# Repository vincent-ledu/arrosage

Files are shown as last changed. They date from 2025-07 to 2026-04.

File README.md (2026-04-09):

# Description

🌍 **This project automates the watering of a garden** using a Raspberry Pi connected to a rainwater collector.

🌊 It monitors water levels with floating switches and controls a solenoid valve and pump to distribute water as needed.

🔧 The system is designed for reliability and ease of installation, using readily available components and open-source software.

🌿 **Goal**: Optimize water usage and reduce manual intervention for garden irrigation.

💡 This project is completely inspired by Frederic JELMONI's project, available here: [Fred's Project](https://www.fred-j.org/index0364.html?p=364)

# Features

- 🌡️ **Retrieves daily temperature forecasts** from Open-Meteo to optimize watering schedules.
- 💦 **Adjusts watering duration and frequency** based on the predicted maximum temperature of the day.
- 🌊 **Displays real-time water tank level** using floating switches.
- 📊 **Shows a history of past watering events** for monitoring and analysis.

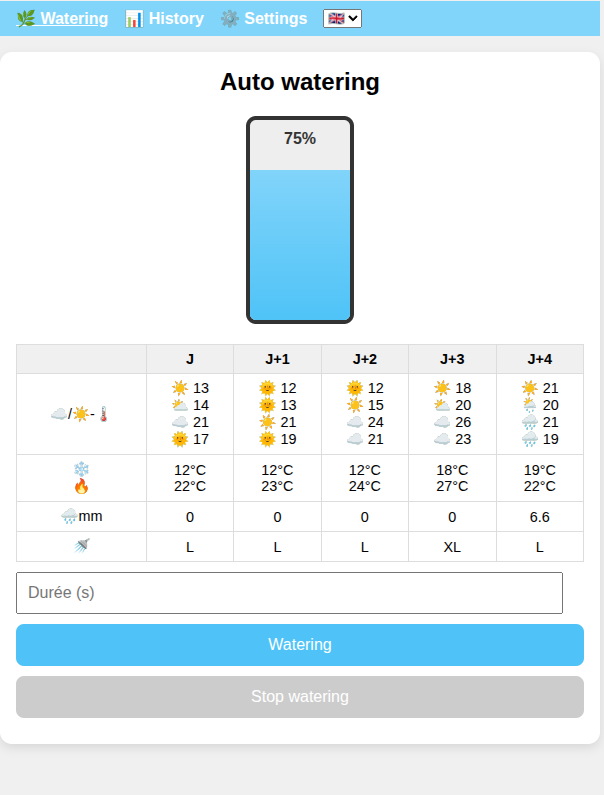
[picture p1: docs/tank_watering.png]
Tank monitor and watering control


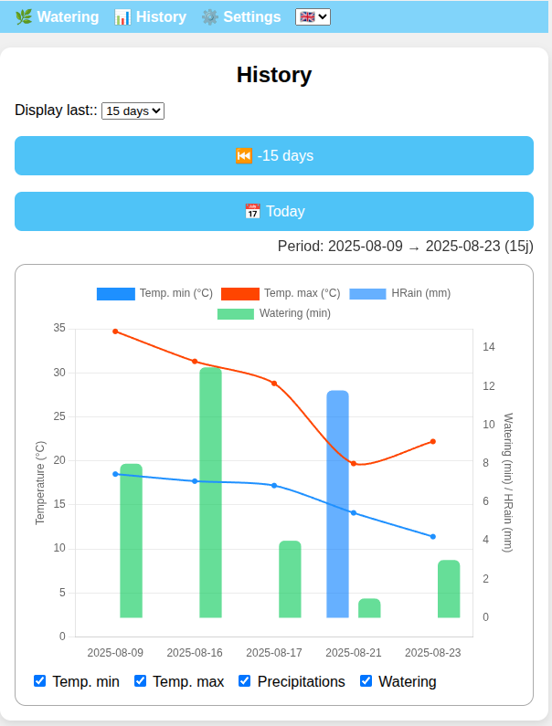
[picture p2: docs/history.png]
Graph of watering history


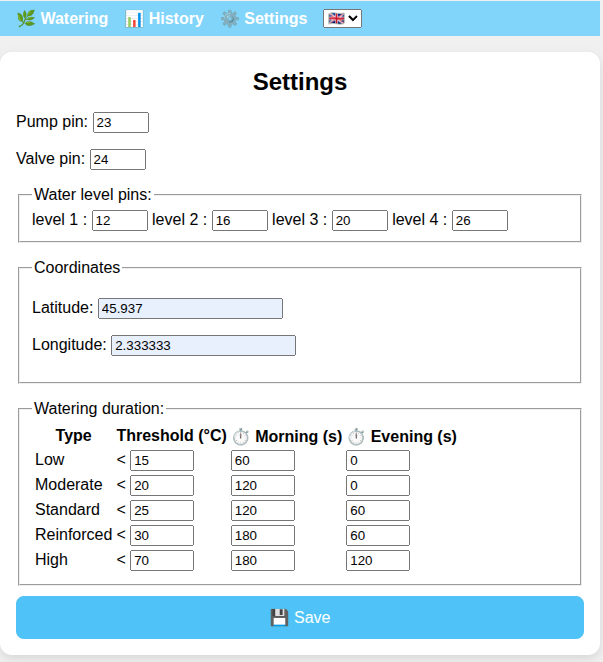
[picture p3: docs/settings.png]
Settings


# Electronic and soldering

## Wiring for water detection in the tank

For this part, the best is to consult [Fred's Project](https://www.fred-j.org/index0364.html?p=364)

My customisation:

- I didn't use hat, I just solder cable directory on resistors, and protect with heat shrink tubes.
- I just use 4 floating switches. I need only these level:
  - Full, to potentielly stop collecting water
  - Empty, to stop all watering process
  - Two intermediates levels, for information
- To compute water level, we count number of floating switch. It simplifies wiring.

Here is the electronic diagram from Frédéric JELMONI's project:
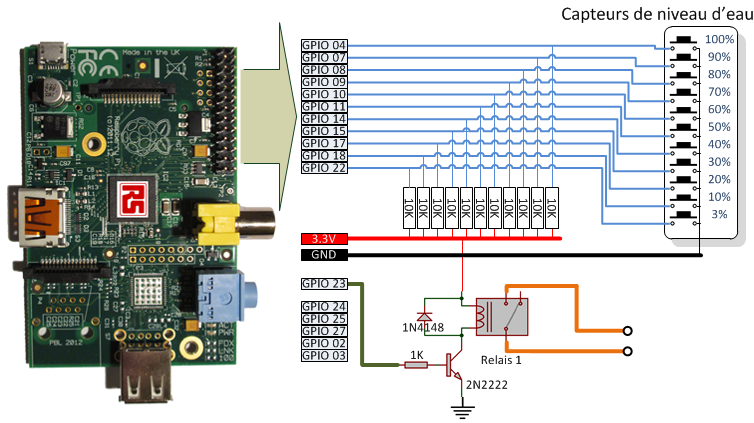
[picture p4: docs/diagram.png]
Wiring diagram


## Wiring for pump and valve

My pump need to be plug in a standard electric outlet.

So, I wire an eletric outlet with the 5V Low Level trigger.

The valve has to be pluged with cable directly to the 5V low level trigger.

# Configuration

🖥️ **Tested on Raspberry Pi 1 and 4.**

🔧 **Middlewares installed:**

- nginx, as reverse proxy and protect access to sensitive action (watering, gpio pin settings, ...) from outside the lan network.
- gunicorn, as wsgi python server. As mentionned when you start a python Flask project, default webserver in Flask is not to use in production.
- mariadb, as database. Tried with SQLite, but it's a big crap, specially for datetime...

⚙️ **Specific Configuration:**

- Adding `www-data` user to the GPIO group

# 🏡 My architecture

```mermaid
flowchart LR
    A(["Internet Box"]) --> B{"Security<br>Reverse<br>Proxy"}
    B --> C["PI<br>Watering project"] & X["Others apps"]
    C --> D("Pump") & E("Valve") & F("Tank")
     A:::Rose
     B:::Peach
     C:::Sky
     X:::Ash
     D:::Aqua
     E:::Aqua
     F:::Aqua
    classDef Rose stroke-width:1px, stroke-dasharray:none, stroke:#FF5978, fill:#FFDFE5, color:#8E2236
    classDef Peach stroke-width:1px, stroke-dasharray:none, stroke:#FBB35A, fill:#FFEFDB, color:#8F632D
    classDef Sky stroke-width:1px, stroke-dasharray:none, stroke:#374D7C, fill:#E2EBFF, color:#374D7C
    classDef Aqua stroke-width:1px, stroke-dasharray:none, stroke:#46EDC8, fill:#DEFFF8, color:#378E7A
    classDef Ash stroke-width:1px, stroke-dasharray:none, stroke:#999999, fill:#EEEEEE, color:#000000
```

## VM for security

Installed middlewares:

- NGinx: Reverse Proxy as unique entry-point, to handle basically on premise hosting redirection
  - It has reinforced nginx settings
  - Handle Let's Encrypt certificate
- Fail2ban: Trap and ip ban bots and malicious scan

## Raspberry

Installed middlewares:

- NGinx:
  - Reverse proxy, with security specific directive to forbid sensitive action coming outside LAN network: Watering, GPIO pin setting, coordinates, ...
  - this nginx configuration file is present in this repository, in deployment folder
- Gunicorn: As mentionned when you start a flask application in development, you must use a wsgi server for production environment.
  - Systemd config file for gunicorn is present in deployment folder.

## Deployment script

See `utils/deploy.sh`

## Crontab

```bash
### morning
0 6 * * * cd /opt/arrosage/current && /opt/arrosage/current/.venv/bin/python scripts/cron.py morning >> /var/log/gunicorn/cron-arrosage.log 2>&1
### evening
0 20 * * * cd /opt/arrosage/current && /opt/arrosage/current/.venv/bin/python scripts/cron.py evening >> /var/log/gunicorn/cron-arrosage.log 2>&1
```

# TODO

- [ ] 🚿 Compute water volume per watering (settings with pump capacity)

# DONE

- [x] 👾 Analyze warning message in venv creation and dependancies installation
- [x] 🏗️ Go to a Domain Driven Design approach
- [x] 🇫🇷/🇬🇧 Fix translation bug
- [x] 🌦️ Give temperature and precipitation forecast for next 3 days
- [x] 🖼️ Add some pictures of the electrical device
- [x] 🌡️ Table from j-0 to J+4, with cloud, morning/evening, temperature
- [x] 🌡️ Get and display min/max temperature of the day
- [x] 📊 Review data model to integrate : start and stop for water tasks, temperature & precip
- [x] 📊 Review graph: add min max temperature, precipitation, last 30 days
- [x] 🔥 Add temperature to history graph
- [x] 💬 Investigate "Message flash" in flask for user error display
- [x] 👾 Fix front (flag, white main zone, textbox width, label for Rain, get current watering task...)
- [x] 📊 Review graph: improve data model
  - [x] #️⃣ create a separate table for temperature, precipitations
  - [x] #️⃣ import data
  - [x] 📊 make a join for history display
- [x] 🏎️ Add data in cache for data of the day
- [x] 🧪 Improve unittest
  - [x] 📊 Bind to test instance database
  - [x] 🧪 Add more unit tests
- [x] 🚚 Review deploy script
  - [x] 🚚 Remove sqlite backup
  - [x] ➕ Add mariadb backup
- [x] 🧊 Prevent watering when temperature < 0°
- [x] 🗓️ Settings for month watering: checks which month watering is enabled
- [x] 🏎️ Improve cached data
  - [x] 📊 Rename existing table to weather_data
  - [x] 📊 Create table to forecat_data
  - [x] ⏱️ Refresh weather data of the day for 6h.
  - [x] 🧪 Unit testing
  - [x] 🏎️ Cache forecat for 4 next days (j+1 to j+4) in table forecast_data
  - [x] ⏱️ Cache forecat data for 6h.
  - [x] ❌ Delete old forecast data
  - [x] 🧪 Unit testing
- [x] 💬 Fix message flash when non page redirect

# Inventory

## Electrical Devices ⚡

- 🍓 **Raspberry Pi (Model 3 here)**  
  [Amazon Link](https://www.amazon.fr/Raspberry-d%C3%A9marrage-dalimentation-Bo%C3%AEtier-Carte/dp/B0D3FNL84M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) ~72€
- 💧 **4 Floating Water Switch to detect water level**  
  [Amazon Link](https://www.amazon.fr/dp/B0DD6L4QP6?ref=ppx_yo2ov_dt_b_fed_asin_title) ~2x10€

- 🔌 **Wires to link from the tank to the Raspberry Pi**  
  [Amazon Link](https://www.amazon.fr/dp/B0087YHNGK?ref=ppx_yo2ov_dt_b_fed_asin_title) ~20€

- 🪛 **10KOhm Resistors**  
  [Amazon Link](https://www.amazon.fr/Innfeeltech-tol%C3%A9rance-r%C3%A9sistance-m%C3%A9tallique-exp%C3%A9riences/dp/B0CL6MDSHV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) ~7€

- 🔋 **5V Low Level Trigger**  
  [Amazon Link](https://www.amazon.fr/dp/B07LB2RQYP?ref=ppx_yo2ov_dt_b_fed_asin_title) ~13€

- 🔧 **Heat Shrink Tubing**  
  [Amazon Link](https://www.amazon.fr/dp/B084GDLSCK?ref=ppx_yo2ov_dt_b_fed_asin_title) ~15€

- 📦 **IP55 Large Box**  
  [Amazon Link](https://www.amazon.fr/dp/B003O2X6T8?ref=ppx_yo2ov_dt_b_fed_asin_title) ~30€

- 🚿 **Solenoid Valve**  
  [Amazon Link](https://www.amazon.fr/dp/B0BRCPP7ZZ?ref=ppx_yo2ov_dt_b_fed_asin_title) ~25€

- 🔌 **Dupont Cables**  
  [Amazon Link](https://www.amazon.fr/Elegoo-Breadboard-Femelle-Longueur-Arduino/dp/B01JD5WCG2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) ~10€

- 🧰 **Breadboard**  
  [Amazon Link](https://www.amazon.fr/sspa/click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) ~7€

- ⚙️ **Metal Angle to screw floating water switch in the tank** [Amazon link](https://www.amazon.fr/Commentfer-Corniere-acier-Longueur-metres/dp/B01N02DVJ0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)

**Total: ~220€**

## Garden Devices 🌳

- 🚰 **Water Pump**  
  [Amazon Link](https://www.amazon.fr/dp/B08MV3VW7S?ref=ppx_yo2ov_dt_b_fed_asin_title) ~80€

- 🌿 **Garden Hose Connection**  
  [Amazon Link](https://www.amazon.fr/dp/B0BZKP7CNV?ref=ppx_yo2ov_dt_b_fed_asin_title) ~10€

- 💦 **Quick Garden Hose Connection**  
  [Amazon Link](https://www.amazon.fr/dp/B09J93FDK2?ref=ppx_yo2ov_dt_b_fed_asin_title) ~10€

**Total: ~100€**

# Installation prerequisites

```bash
apt update
apt install nginx mariadb-server build-essential python3-dev
mkdir /run/gunicorn
chown www-data:www-data /run/gunicorn
usermod -a -G gpio www-data
mysql -u root -p < utils/create-database.sql
```

## Tools 🔧

- 🔩 Screwdrivers
- 🔥 Soldering Iron
- 🧲 Tin
- 🔩 Screws
- 🔥 Heat Gun

# Credits

Pictures and diagrams from Frédéric JELMONI is used with his consent.

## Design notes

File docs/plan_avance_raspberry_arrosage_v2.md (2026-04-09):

# Plan avancé Raspberry Pi arrosage (v2)

## 🔋 Schéma condensateurs

5V ───┬──[100nF]── GND
      │
      └──[470µF]── GND

3.3V ───┬──[100nF]── GND
        │
        └──[100µF]── GND

GPIO ───┬── flotteur ─── GND
        │
       [100nF]
        │
       GND

230V : snubber RC parallèle

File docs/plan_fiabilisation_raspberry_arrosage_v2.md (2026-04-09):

# Plan de fiabilisation Raspberry Pi arrosage (v2)

## 🔋 Condensateurs

### 5V relais
5V ───┬──[100nF]── GND
      │
      └──[470µF]── GND

### 3.3V capteurs
3.3V ───┬──[100nF]── GND
        │
        └──[100µF]── GND

### GPIO flotteurs
GPIO ───┬── flotteur ─── GND
        │
       [100nF]
        │
       GND

### 230V
Snubber RC sur charge

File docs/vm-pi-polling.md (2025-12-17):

# VM side – Pi polling & cache

Objectif : l’UI/back reste disponible même si le Raspberry Pi est instable.
La VM poll périodiquement le `pi-service` et stocke le dernier état connu en DB.

## Variables d’environnement (VM)

Dans `/etc/default/arrosage` :

- `PI_SERVICE_URL=http://<pi-host>` (obligatoire pour activer le mode Pi)
- `PI_SERVICE_TOKEN=...` (recommandé)
- `PI_SERVICE_TIMEOUT_CONNECT=0.5`
- `PI_SERVICE_TIMEOUT_READ=1.0`
- `PI_SNAPSHOT_MAX_AGE_SEC=120`

## Cache en base

- Table `device_snapshot` : dernier état connu (niveau d’eau, watering, last_seen_at…)
- Table `device_command_log` : audit des commandes start/stop

Migration Alembic : `migrations/versions/7_0f1caa2f4cbb_create_device_snapshot_and_logs.py`

## Poller

Script : `scripts/pi_poll.py`

Option systemd timer (recommandé) :

- Service : `deployment/systemd/arrosage-pi-poll.service`
- Timer : `deployment/systemd/arrosage-pi-poll.timer`

Installation (sur la VM) :

- `sudo cp /opt/arrosage/current/deployment/systemd/arrosage-pi-poll.service /etc/systemd/system/`
- `sudo cp /opt/arrosage/current/deployment/systemd/arrosage-pi-poll.timer /etc/systemd/system/`
- `sudo systemctl daemon-reload`
- `sudo systemctl enable --now arrosage-pi-poll.timer`

## Endpoints VM

- `GET /api/water-level` : sert le cache DB (fallback 0 si pas de cache)
- `GET /api/device/snapshot` : détail du snapshot + stale/age
- `GET /api/device/gpio?verbose=1` : proxy live vers le Pi (si disponible)

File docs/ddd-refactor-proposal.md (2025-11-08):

# Proposition de refonte Domain-Driven Design

## Constats sur l'existant

* `app/app.py` concentre la configuration Flask, des appels HTTP externes, des accès SQLAlchemy et la gestion temps-réel du matériel (pompe, vannes, flotteurs). 【F:app/app.py†L1-L454】
* Les accès à la base (`app/db`) exposent directement l'ORM aux couches supérieures, ce qui couple l'API au schéma relationnel. 【F:app/db/db_tasks.py†L18-L80】
* Le contrôle matériel est instancié en global selon l'environnement, ce qui rend difficile le remplacement dans des scénarios métiers. 【F:app/app.py†L25-L37】

Ces éléments mélangent responsabilités applicatives, domaine et infrastructure, compliquant l'évolution vers de nouvelles règles d'arrosage.

## Bounded contexts proposés

| Contexte | Responsabilité | Entités / Agrégats | Interfaces externes |
| --- | --- | --- | --- |
| **WateringControl** | Pilotage des tâches d'arrosage (durée, annulation, statut) | `WateringTask`, `WateringSchedule` | GPIO/contrôleur matériel |
| **WaterResource** | Mesure et alerte sur le niveau d'eau disponible | `TankLevel`, `WaterAvailability` | Capteurs de niveau |
| **WeatherInsight** | Collecte et agrégation des prévisions météo | `DailyForecast`, `PartDayForecast` | API Open-Meteo |
| **SystemConfiguration** | Paramétrage utilisateur (coordonnées, mois actifs, seuils) | `WateringPolicy` | Fichier de configuration |

Chaque contexte expose des services applicatifs explicites et des ports (interfaces) vers l'infrastructure.

## Strate d'architecture (hexagone inspiré DDD)

```
domain/
  watering/
    entities.py        # WateringTask, TankLevelSnapshot
    policies.py        # Règles métier (mois actifs, températures)
    services.py        # e.g. WateringScheduler
  weather/
    value_objects.py
    services.py        # Agrégations sur les prévisions
  configuration/
    repositories.py    # Port vers le stockage de configuration
application/
  watering/
    commands.py        # StartWatering, StopWatering
    queries.py         # FetchCurrentTask
    handlers.py        # Orchestration des entités et ports
infrastructure/
  persistence/
    watering_task_repository.py
    weather_repository.py
  devices/
    gpio_controller.py
  external/
    open_meteo_client.py
interfaces/
  http/
    flask/
      routes/
  cli/
```

* **Domain** : entités riches, règles (`WateringPolicy`) calculant la durée selon la température, validations de disponibilité d'eau.
* **Application** : orchestrateurs qui orchestrent les ports (`WateringTaskRepository`, `WeatherForecastProvider`, `DeviceController`). Les commandes/queries remplacent les routes lourdes de `app/app.py`. 【F:app/app.py†L280-L433】
* **Infrastructure** : implémentations SQLAlchemy/GPIO/API des ports. `db_tasks` devient une implémentation de `WateringTaskRepository`. 【F:app/db/db_tasks.py†L18-L80】
* **Interfaces** : routes Flask deviennent de simples adaptateurs qui traduisent HTTP ↔ commandes applicatives.

## Ports et adapters clés

| Port | Contrat | Adapter initial |
| --- | --- | --- |
| `DeviceController` | `open_water(duration)`, `close_water()`, `read_tank_level()` | `GPIOControl` / `FakeControl` (déplacés sous `infrastructure.devices`) 【F:app/app.py†L25-L37】|
| `WateringTaskRepository` | CRUD des tâches, recherche par statut | `db_tasks` (renommé, injecté) 【F:app/db/db_tasks.py†L18-L80】|
| `ForecastProvider` | Récupération des prévisions brutes | `services.weather.fetch_open_meteo` |
| `ForecastCache` | Stockage court-terme des prévisions agrégées | `db_forecast_data`, `db_weather_data` |
| `ConfigurationRepository` | Lecture/écriture des paramètres | `config.config` |

## Règles métier explicitées

1. **Validation de fenêtre d'arrosage** : isoler dans `WateringPolicy.can_start_watering(month, min_temperature, tank_level)` les règles dispersées sur la route `/api/command/open-water`. 【F:app/app.py†L343-L405】
2. **Gestion des tâches** : encapsuler la logique d'annulation et d'update dans un service `WateringTaskManager` afin d'éviter le couplage au threading dans l'adapter HTTP. 【F:app/app.py†L280-L414】
3. **Agrégation météo** : déplacer l'appel Open-Meteo dans un `ForecastService` qui gère fraicheur & persistence. 【F:app/app.py†L115-L214】

## Stratégie de migration

1. **Cartographier** les routes existantes vers des cas d'usage (e.g. `OpenWaterDelay` → commande `StartManualWatering`).
2. **Introduire** les ports (interfaces) dans un nouveau module `domain` tout en continuant d'utiliser les implémentations existantes.
3. **Déplacer progressivement** la logique métier dans les services du domaine en ajoutant des tests unitaires ciblés (durées, autorisations, validations température).
4. **Créer** une fine couche application (handlers) orchestrant les ports; adapter les routes Flask pour appeler ces handlers.
5. **Refactoriser** les modules `db_*`, `control_*`, `services.weather` en adaptateurs conformes aux ports, sans modifier immédiatement les dépendances externes.
6. **Nettoyer** `app/app.py` pour n'y laisser que le bootstrap Flask, l'injection des dépendances et le wiring des routes.

## Livrables intermédiaires recommandés

* Tests de régression sur les routes critiques (`/api/command/open-water`, `/api/water-level`, `/api/forecast`).
* Documentation d'architecture actualisée décrivant les contextes et ports.
* Scripts de migration de la base si le modèle d'entité `WateringTask` évolue.

Cette approche permet d'encapsuler la logique métier, de préparer l'ajout de nouvelles règles (par exemple volume pompé par arrosage) et de faciliter la substitution des capteurs ou de l'API météo.

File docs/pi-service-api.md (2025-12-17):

# Pi Service (Device Agent) – REST Contract

Objectif : service **minimaliste** sur Raspberry Pi, **sans DB** et sans UI, qui pilote uniquement le GPIO.

## Sécurité / sûreté (recommandations)

- **Arrêt automatique local (timer)** : toute commande de démarrage doit planifier un arrêt côté Pi (même si le réseau tombe).
- **Durée max** : refuser les durées > `PI_MAX_WATERING_DURATION_SEC` (défaut `900` = 15 minutes).
- **Auth simple** : token en header (`Authorization: Bearer <token>` ou `X-API-Token: <token>`), via `PI_SERVICE_TOKEN`.
- **Allowlist LAN** : recommandé via Nginx (ou firewall) pour limiter l’accès aux endpoints de commande.

## Endpoints

### Health
- `GET /healthz` → `200` si le service répond et le GPIO est joignable.

### Niveau d’eau
- `GET /v1/water-level` → `200`
  - Réponse : `{ "level_percent": 0|25|50|75|100, "ts": "..." }`

### Statut arrosage
- `GET /v1/status` → `200`
  - Réponse :
    - `watering`: bool
    - `remaining_sec`: int
    - `since`, `scheduled_stop_at`: ISO8601 ou `null`
    - `water_level_percent`: int

### Démarrer
- `POST /v1/watering/start` → `202`
  - Body JSON : `{ "duration_sec": 60 }`
  - Header optionnel : `Idempotency-Key: <uuid|string>`
  - Erreurs :
    - `400` durée manquante / invalide / > max
    - `409` si déjà en cours (sauf idempotence)

### Stop
- `POST /v1/watering/stop` → `200`
  - Réponse : `{ "stopped": true|false }`

### GPIO (config + état)
- `GET /v1/gpio` → `200`
  - Réponse par défaut : pins configurés
  - `?verbose=1` : ajoute `levels_state` (lecture GPIO des capteurs) + `outputs` (état logique pump/valve)

## Lancer le service (dev)

Dans ce repo, le code est sous `src/` (comme en prod où `src/` est copié à la racine du release).
Pour lancer depuis la racine du repo :

- `(.venv) gunicorn --chdir src pi_service.wsgi:app --bind 0.0.0.0:8000`

Variables usuelles :

- `ARROSAGE_CONFIG_FILE=/etc/arrosage/config.json`
- `PI_SERVICE_TOKEN=...`
- `PI_MAX_WATERING_DURATION_SEC=900`

## Déploiement (systemd + nginx)

- Unité systemd : `deployment/systemd/arrosage-pi.service`
  - Socket gunicorn : `unix:/run/gunicorn/gunicorn_arrosage_pi.sock`
- Nginx : `deployment/nginx/arrosage-pi.conf`
  - `/healthz` et `/healthcheck` ouverts
  - le reste est restreint au LAN (RFC1918), à adapter à ton plan d’adressage
- Fichier d’environnement : `deployment/etc/default/arrosage-pi`
  - `ARROSAGE_CONFIG_FILE` doit pointer vers le `config.json` local au Pi

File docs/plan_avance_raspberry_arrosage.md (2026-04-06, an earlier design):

# Fiabilisation avancée installation Raspberry Pi arrosage

## 🎯 Objectif
Version robuste, maintenable, testable avec :
- mapping GPIO clair
- code couleur câblage
- schémas électriques détaillés

---

# 🧠 1. Mapping GPIO recommandé

| Fonction | GPIO BCM | Pin physique |
|---|---|---|
| Flotteur 1 (bas) | GPIO17 | Pin 11 |
| Flotteur 2 | GPIO27 | Pin 13 |
| Flotteur 3 | GPIO22 | Pin 15 |
| Flotteur 4 (haut) | GPIO23 | Pin 16 |
| Relais pompe | GPIO24 | Pin 18 |
| Relais vanne | GPIO25 | Pin 22 |
| GND | - | Pins 6, 9, 14 |
| 3.3V | - | Pin 1 |
| 5V | - | Pin 2 |

---

# 🎨 2. Code couleur recommandé

| Signal | Couleur |
|---|---|
| 3.3V | Orange |
| 5V | Rouge |
| GND | Noir |
| Entrées flotteurs | Bleu |
| Sorties relais | Jaune |
| 230V phase | Marron |
| 230V neutre | Bleu |
| Terre | Vert/Jaune |

---

# 🔌 3. Schéma bloc complet

```
[Flotteurs] 
   ↓
[Bornier capteurs]
   ↓
[Breakout GPIO]
   ↓
[Raspberry Pi]

GPIO sorties
   ↓
[Relais]
   ↓
Pompe / électrovanne
```

---

# ⚡ 4. Schéma électrique capteurs

```
3.3V
  │
 [10kΩ]
  │
GPIO ──────── Flotteur ──────── GND
```

### Détail
- Résistance pull-up 10kΩ
- Contact flotteur vers GND

---

# ⚡ 5. Schéma électrique relais

## Partie logique (basse tension)

```
GPIO24 ─── IN1 (pompe)
GPIO25 ─── IN2 (vanne)

5V ─────── VCC relais
GND ────── GND relais
```

## Partie puissance (230V)

```
Phase ─── COM relais
NO ────── Pompe
Neutre ── Pompe direct
Terre ─── Pompe direct
```

---

# 🔧 6. Types de fils

| Usage | Type |
|---|---|
| GPIO / capteurs | AWG22 |
| Alim 5V | AWG22 |
| 230V | 1.5 mm² |

---

# 🧪 7. Banc de test

## Schéma

```
Switch ─── GPIO ─── GND

GPIO ─── LED ─── 220Ω ─── GND
```

---

# 🧱 8. Organisation boîtier

## Zone 1 (basse tension)
- Raspberry
- breakout
- capteurs

## Zone 2 (230V)
- relais
- alimentation secteur

---

# 🧩 9. Bonnes pratiques

- Ferrules sur tous les fils
- Aucun Dupont en prod
- Presse-étoupes obligatoires
- Séparation physique 230V / 3.3V

---

# ✅ 10. Résultat

- Maintenance rapide
- Debug facile
- Fiabilité extérieure

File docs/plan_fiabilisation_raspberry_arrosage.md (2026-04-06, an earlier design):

# Fiabilisation d’une installation Raspberry Pi (arrosage) — Plan & Schémas

## Objectif
Rendre l’installation **modulaire, maintenable et fiable** en extérieur :
- Retirer le Raspberry sans dessouder
- Tester chaque bloc indépendamment
- Séparer basse tension / 230V
- Réduire les faux contacts et parasites

---

## Architecture cible

```
Raspberry Pi
   ↓ (nappe 40 pins)
Breakout GPIO à vis
   ↓
 ├── Bloc capteurs (flotteurs)
 └── Bloc relais (pompe + électrovanne)

Banc de test séparé :
 ├── Interrupteurs (simulation flotteurs)
 └── LEDs (simulation sorties)
```

---

## Règles générales

### Types de fils
- **AWG22 (≈0.34 mm²)** → tous les signaux (GPIO, capteurs, relais)
- **1.5 mm²** → uniquement le 230V

### Connexions
- ✔ Borniers à vis → partout
- ✔ Ferrules (embouts) → sur tous les fils AWG22
- ❌ Dupont → uniquement pour banc de test
- ❌ Soudure → éviter dans la boîte finale

---

## Étape 1 — Breakout GPIO

### Objectif
Supprimer toute connexion directe fragile sur le Raspberry

### Câblage
```
Raspberry Pi
   ↓ nappe 40 pins
Breakout GPIO à vis
```

---

## Étape 2 — Bloc capteurs (flotteurs)

### Schéma logique (pull-up)

```
3.3V ──[10kΩ]── GPIO ─── flotteur ─── GND
```

### Câblage réel

```
[Flotteur]
   ↓ (AWG22)
Bornier capteurs
   ↓
Breakout GPIO
```

### Connexions
- Flotteur → GPIO (via bornier)
- Flotteur → GND
- Résistance 10kΩ entre GPIO et 3.3V

### Mise en œuvre
- Résistances sur petite plaque proto
- Tous les fils AWG22 avec ferrules
- Tout vissé (pas de fils nus)

---

## Étape 3 — Bloc relais (pompe + électrovanne)

### Basse tension

```
GPIO ─── IN1 relais (pompe)
GPIO ─── IN2 relais (vanne)

5V ─── VCC relais
GND ─── GND relais
```

### 230V

```
Phase ─── COM relais
NO ─── pompe / vanne
Neutre ─── direct
Terre ─── direct (si applicable)
```

### Fils
- GPIO → AWG22
- 230V → 1.5 mm²

### Connexions
- Tout vissé
- Aucun fil soudé côté puissance

---

## Étape 4 — Organisation du boîtier

### Séparation obligatoire

```
[ Zone basse tension ]
- Raspberry
- Breakout
- Capteurs

[ Zone 230V ]
- Relais
- Pompe
- Électrovanne
```

### Bonnes pratiques
- Presse-étoupes
- Fils fixés
- Aucun fil en traction

---

## Étape 5 — Banc de test

### Schéma

```
Interrupteur ─── GPIO ─── GND
GPIO ─── LED ─── résistance ─── GND
```

### Matériel
- 4 interrupteurs (flotteurs)
- 2 LEDs (sorties)
- résistances 220Ω

---

## Étape 6 — Ordre de migration

1. Créer le banc de test
2. Installer breakout GPIO
3. Refaire bloc capteurs
4. Refaire bloc relais
5. Réorganiser boîtier

---

## Résultat attendu

- Raspberry extractible rapidement
- Diagnostic facile
- Moins de parasites
- Installation durable extérieur

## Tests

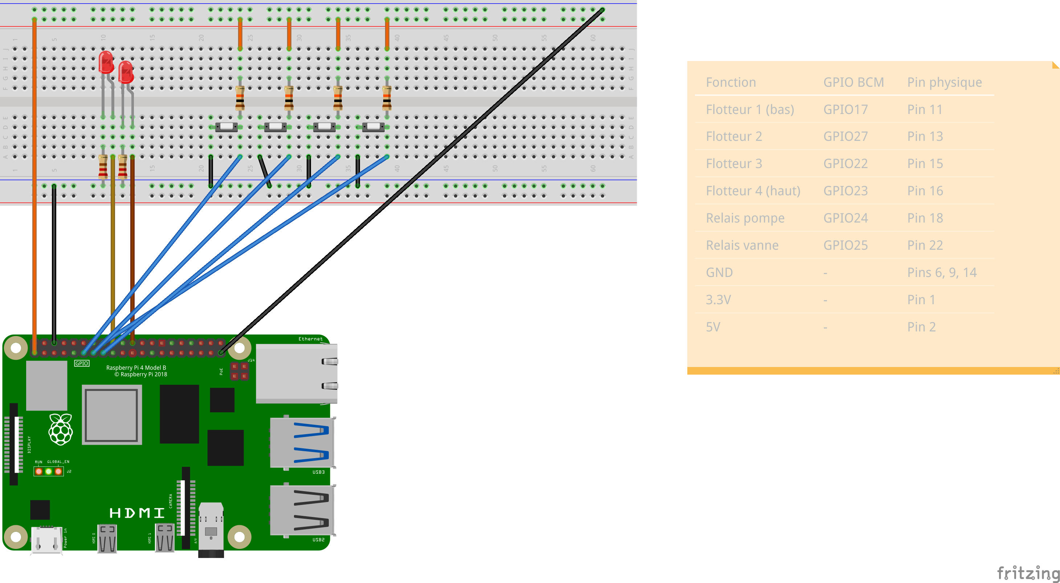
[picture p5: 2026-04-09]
docs/test_pi_breadboard.png

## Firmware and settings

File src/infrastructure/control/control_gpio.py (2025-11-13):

import RPi.GPIO as GPIO
import logging
import time

from control.control_interface import Control
import config.config as local_config

logger = logging.getLogger(__name__)


class GPIOControl(Control):
    def __init__(self):
        self.control_state = {"pump": None, "valve": None, "levels": []}

    @property
    def control_state(self):
        return self._control_state

    @control_state.setter
    def control_state(self, value):
        if not isinstance(value, dict):
            raise ValueError("control_state must be a dictionary")
        self._control_state = value

    def setup(self):
        # Initialisation générale (mode BCM)
        GPIO.setmode(GPIO.BCM)
        GPIO.setwarnings(False)
        config = local_config.load_config()
        self.releaseAll()

        self.control_state["pump"] = config["pump"]
        self.control_state["valve"] = config["valve"]
        self.control_state["levels"] = config["levels"]

        # Configure les sorties
        GPIO.setup(self.control_state["pump"], GPIO.OUT)
        GPIO.setup(self.control_state["valve"], GPIO.OUT)

        # Configure les capteurs de niveau en entrée avec pull-down
        for pin in self.control_state["levels"]:
            GPIO.setup(pin, GPIO.IN, pull_up_down=GPIO.PUD_DOWN)

        logger.info("✅ GPIO initialized with:")
        logger.info(f"  Pump : GPIO {self.control_state['pump']}")
        logger.info(f"  Valve : GPIO {self.control_state['valve']}")
        logger.info(f"  Levels : {self.control_state['levels']}")

    def releaseAll(self):
        all_pins = [
            self.control_state["pump"],
            self.control_state["valve"],
        ] + self.control_state["levels"]
        for pin in all_pins:
            if pin is not None:
                try:
                    GPIO.cleanup(pin)  # free pin if it was used
                except Exception:
                    pass

    def openWater(self):
        valve_pin = self.control_state["valve"]
        pump_pin = self.control_state["pump"]
        logger.info("Opening valve (GPIO %s)", valve_pin)
        GPIO.output(valve_pin, GPIO.HIGH)
        time.sleep(2)
        logger.info("Starting pump (GPIO %s)", pump_pin)
        GPIO.output(pump_pin, GPIO.HIGH)

    def closeWater(self):
        pump_pin = self.control_state["pump"]
        valve_pin = self.control_state["valve"]
        logger.info("Stopping pump (GPIO %s)", pump_pin)
        GPIO.output(pump_pin, GPIO.LOW)
        time.sleep(2)
        logger.info("Closing valve (GPIO %s)", valve_pin)
        GPIO.output(valve_pin, GPIO.LOW)

    def debugWaterLevels(self):
        water_states = {}
        for i in range(4):
            water_states[f"level_{i}"] = {
                "gpio_pin": self.control_state["levels"][i],
                "state": GPIO.input(self.control_state["levels"][i]),
            }
        return water_states

    def getLevel(self):
        level = 0
        for i in range(4):
            logger.info(f"Checking level {i}")
            if GPIO.input(self.control_state["levels"][i]):
                level += 1
        return level

    def cleanup(self):
        GPIO.cleanup()
        logger.info("GPIO cleaned up successfully.")

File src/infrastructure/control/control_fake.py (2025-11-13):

import logging
from control.control_interface import Control

logger = logging.getLogger(__name__)


class FakeControl(Control):
    def __init__(self):
        self._control_state = {"pump": None, "valve": None, "levels": []}
        self._level = 4  # Default level for testing

    @property
    def level(self):
        return self._level

    @level.setter
    def level(self, value):
        logger.debug(f"Setting level to {value}")
        if not isinstance(value, int) or value < 0:
            raise ValueError("level must be a positive integer")
        self._level = value

    @property
    def control_state(self):
        return self._control_state

    @control_state.setter
    def control_state(self, value):
        if not isinstance(value, dict):
            raise ValueError("control_state must be a dictionary")
        self._control_state = value

    def releaseAll(self):
        pass

    def openWater(self):
        logger.info("FAKE: valve opened")
        logger.info("FAKE: pump started")

    def closeWater(self):
        logger.info("FAKE: pump stopped")
        logger.info("FAKE: valve closed")

    def debugWaterLevels(self):
        water_states = {}
        for i in range(4):
            water_states[f"level_{i}"] = {"gpio_pin": "fake_pin", "state": "fake_state"}
        return water_states

    def getLevel(self):
        return self.level

    def cleanup(self):
        pass

    def setup(self):
        pass

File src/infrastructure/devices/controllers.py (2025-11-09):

from __future__ import annotations

import importlib
import os
import sys
from datetime import datetime, timezone

from domain.watering.entities import TankLevelSnapshot
from domain.watering.ports import DeviceController, TankLevelSensor


def _resolve_control_impl():
    base_control = importlib.import_module("infrastructure.control")
    sys.modules.setdefault("control", base_control)
    sys.modules.setdefault(
        "control.control_interface",
        importlib.import_module("infrastructure.control.control_interface"),
    )

    environment = os.environ.get("FLASK_ENV", "production")
    if environment in {"development", "test"}:
        fake_module = importlib.import_module("infrastructure.control.control_fake")
        sys.modules.setdefault("control.control_fake", fake_module)

        FakeControl = getattr(fake_module, "FakeControl")

        return FakeControl

    try:  # pragma: no cover - hardware access
        gpio_module = importlib.import_module("infrastructure.control.control_gpio")
        sys.modules.setdefault("control.control_gpio", gpio_module)

        GPIOControl = getattr(gpio_module, "GPIOControl")

        return GPIOControl
    except (ModuleNotFoundError, RuntimeError):
        fake_module = importlib.import_module("infrastructure.control.control_fake")
        sys.modules.setdefault("control.control_fake", fake_module)

        FakeControl = getattr(fake_module, "FakeControl")

        return FakeControl


ControlImpl = _resolve_control_impl()


class DeviceControllerAdapter(DeviceController):
    def __init__(self) -> None:
        self._control = ControlImpl()

    def setup(self) -> None:
        self._control.setup()

    def open_water(self) -> None:
        self._control.openWater()

    def close_water(self) -> None:
        self._control.closeWater()

    def get_level(self) -> float:
        return float(self.getLevel())

    # Compatibilité ascendante : certains tests patchent getLevel directement
    def getLevel(self) -> float:  # pragma: no cover - shim
        return float(self._control.getLevel())

    def debug_water_levels(self):
        return self._control.debugWaterLevels()

    def cleanup(self) -> None:
        self._control.cleanup()


class DeviceTankLevelSensor(TankLevelSensor):
    def __init__(self, controller: DeviceController) -> None:
        self._controller = controller

    def snapshot(self) -> TankLevelSnapshot:
        level_raw = self._controller.get_level()
        measured_at = datetime.now(timezone.utc)
        return TankLevelSnapshot(level_percent=level_raw * 25, measured_at=measured_at)


def create_device_controller() -> DeviceControllerAdapter:
    controller = DeviceControllerAdapter()
    controller.setup()
    return controller

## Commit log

2025-07-07 invert pump & valve, and add timeout between closure
2025-07-22 add:\n -internalisation\n- unit testing\n- better settings for watering
    [babel.cfg]
2025-07-22 fix typo in gpio controler
    [control_gpio.py]
2025-08-08 floor temperature value to fit in width
2025-08-18 docs: dump current sqlite schema
2025-08-23 fix current task. remaining bug on label Rain
2025-08-25 complete test coverage, fix bug in saving weather data, fix some other bugs
    [control_gpio.py]
2025-08-26 add missing translation for error message. Add no watering feature if temperature is too low.
2025-10-03 add flash message when temperature is too low (#22)
2025-11-09 finished refacto (#25)
    [babel.cfg]
2026-04-06 add doc for better wiring
2026-04-09 add docs
    [test_pi_breadboard.fzz]
2026-04-23 update doc
    [real_wiring.fzz, test_pi_breadboard.fzz, test_pi_breadboard_optimized.fzz]
